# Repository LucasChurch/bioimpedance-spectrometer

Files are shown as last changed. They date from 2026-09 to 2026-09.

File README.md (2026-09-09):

# Bioimpedance Spectrometer Development Board
*Bench/research instrument. Not a certified medical device. Not for patient, diagnostic, or clinical use.*

## Overview

A discrete multi-frequency tetrapolar bioimpedance spectroscopy system. The intent of this project is to evaluate several bioimpedance current-source topologies from the literature via simulation, and validate the strongest candidate on a development board. Benchmarking results will be performed first against a resistor phantom and later on tissue. The board includes a low-noise, precision, analog front-end, and an STM32G0 microcontroller for digital lock-in filtering via a Goertzel filter, as well as the synchronous control of the excitation and sense chains.

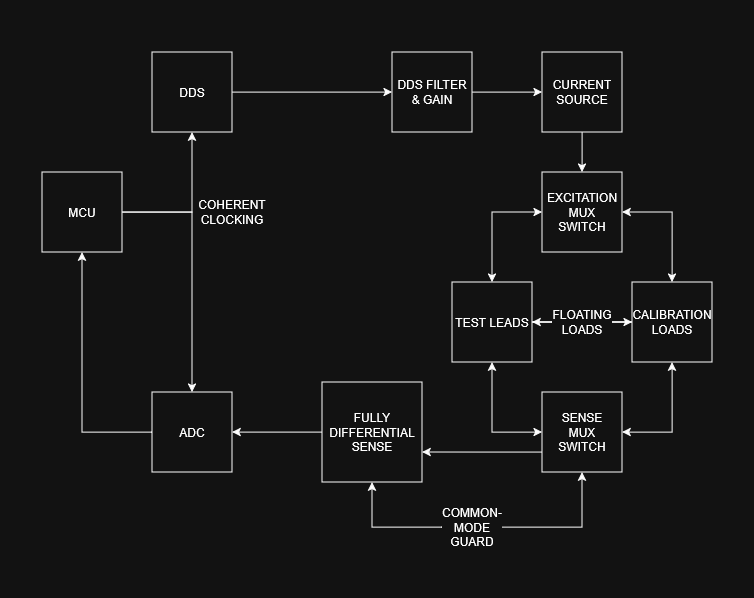
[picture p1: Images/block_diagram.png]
Block Diagram


## Quick Links

- [Schematic (PDF)](CAD/Bioimpedance%20Spectrometer/Outputs/Schematic%20PDF/BioZSpec.pdf)
- [PCB 3D Model (STEP)](CAD/Bioimpedance%20Spectrometer/Outputs/ExportSTEP/BioZ.step)
- [Bill of Materials](CAD/Bioimpedance%20Spectrometer/Outputs/BOM/Bill%20of%20Materials-BioZSpec.xlsx)

## Board Features

- **Measurement** - Multi-frequency bioimpedance spectroscopy. Software adjustable up to 250 kHz (default frequencies 10/50/100/250 kHz). Precision and repeatability designed to 0.25Ω magnitude accuracy and 0.2° phase accuracy. Can be pushed to 400 kHz.
- **Electrodes** - Tetrapolar (Kelvin connected) stainless steel dry contacts
- **Current Source** - Custom mirrored enhanced Howland current pump, 100µA RMS target. Simulated to <0.1% current deviation up to 10kOhm load at 250 kHz.
- **Sense Chain** - Fully differential, common-mode guarded, anti-aliasing filter
- **ADC** - 14-bit, 1 MSPS differential SAR ADC 
- **Excitation Waveform** - 16 MHz DDS-generated sine wave
- **Demodulation** - Software lock-in demodulation (I/Q) via Goertzel filter, coherent excitation/sampling/reference with a 48 MHz oscillator 
- **Calibration** - Three on-board precision complex loads for drift correction. External fixture for electrode compensation.
- **Power** - Rechargeable LiPo cell via USB-C. 5V boost charge pump for excitation. Software-controlled high-side switch for analog chain for power saving
- **MCU** - STM32G071

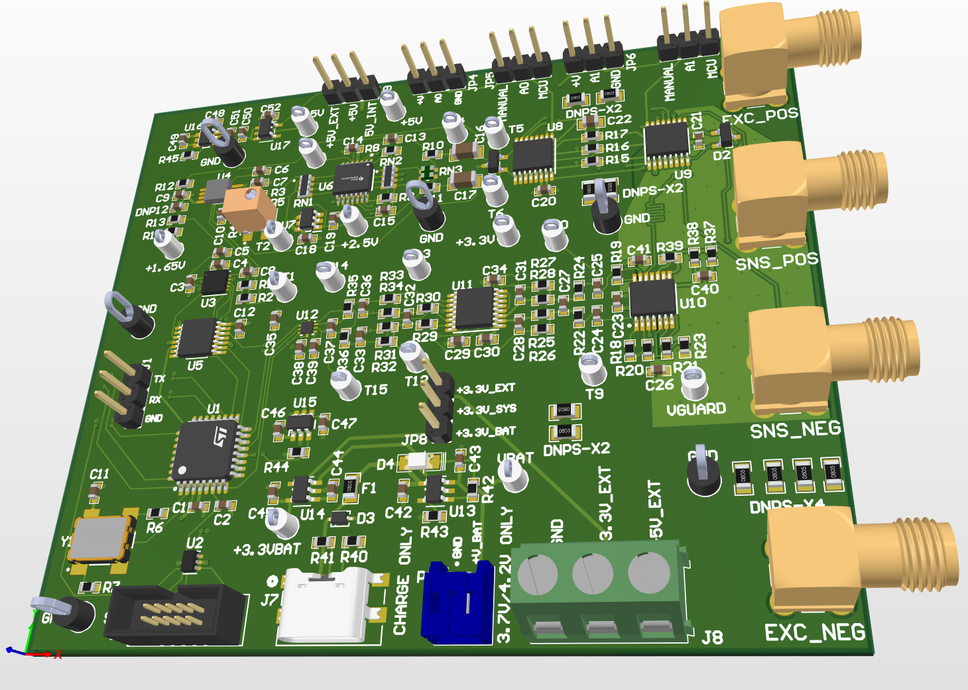
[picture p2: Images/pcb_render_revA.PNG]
PCB 3D Model


## Roadmap

- [x] Research
- [x] Requirements
- [x] Simulation / Schematic Capture
- [x] Layout
- [x] Board & Parts Acquisition
- [x] Calibration Jigs
- [ ] Firmware (*in progress*)
- [ ] Assembly
- [ ] Bring-up
- [ ] Design Verification & Benchmarking
- [ ] Final Documentation

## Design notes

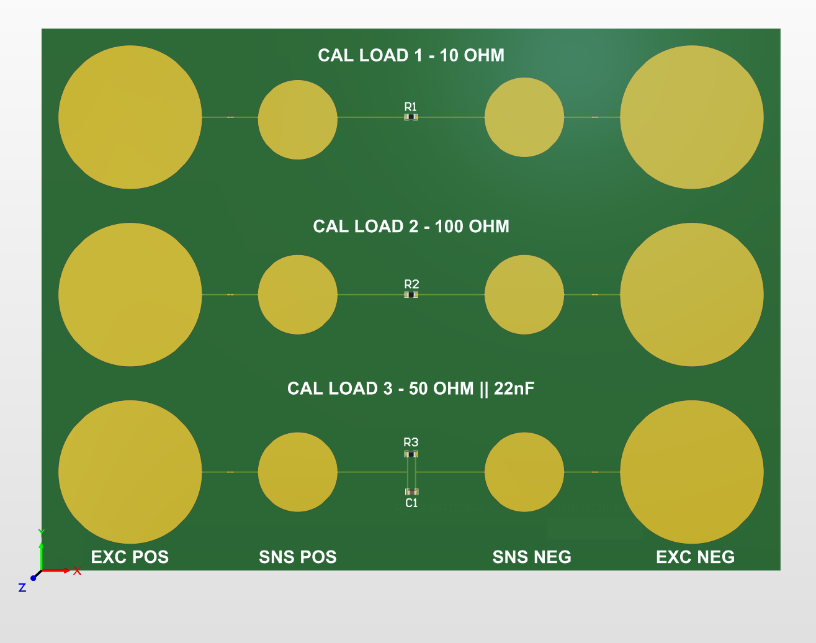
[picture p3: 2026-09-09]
Images/electrode_cal_jig.PNG

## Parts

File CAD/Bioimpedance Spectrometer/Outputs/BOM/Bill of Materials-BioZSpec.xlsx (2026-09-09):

Comment | Description | Designator | Footprint | LibRef | Quantity
10uF | CAP CER 10uF 6.3V X5R 0603, CAP CER 10UF 10V X7R 0603 | C1, C4, C14, C30, C35, C38, C39, C44, C45, C48, C50, C52 | 0603-CAP | CGA3E2C0G1H472J080AA | 12
100nF | CAP CER 100 NF 50V X7R 0603 | C2, C3, C5, C9, C11, C18, C19, C20, C21, C23, C29, C34, C40, C51 | 0603-CAP | CGA3E2C0G1H472J080AA | 14
1nF | CAP CER 1000 PF 50V C0G 0603 | C6, C37, C47 | 0603-CAP | CGA3E2C0G1H472J080AA | 3
100pF | CAP CER 100 PF 50V C0G 0603 | C7 | 0603-CAP | CGA3E2C0G1H472J080AA | 1
2.2uF | CAP CER 2.2UF 35V X5R 0603 | C8, C12, C24, C25, C42, C43, C46 | 0603-CAP | CGA3E2C0G1H472J080AA | 7
0.22uF | CAP CER 0.22UF 25V X7R 0603 | C10, C49 | 0603-CAP | CGA3E2C0G1H472J080AA | 2
10pF C0G | CAP CER 10PF 50V C0G 0603 | C13, C15 | 0603-CAP | CGA3E2C0G1H472J080AA | 2
100nF C0G 1% | CAP CER 0.1UF 1% 50V C0G/NP0 1206 | C16, C17 | 1206-CAP | GRM31C5C1H104JA01L | 2
22nF C0G 1% | CAP CER 0.022UF 50V C0G/NP0 0805 | C22 | 0805-CAP | GCM21B5C1H223JA16L | 1
10pF | CAP CER 10PF 50V C0G/NPO 0603 | C26, C41 | 0603-CAP | CGA3E2C0G1H472J080AA | 2
470pF | CAP CER 470PF 50V C0G 0603 | C27, C32 | 0603-CAP | CGA3E2C0G1H472J080AA | 2
82pF | CAP CER 82PF 50V C0G 0603 | C28, C31, C33, C36 | 0603-CAP | CGA3E2C0G1H472J080AA | 4
RCLAMP04022S.C |  | D1, D2 | SOT-23 3L | RCLAMP04022S.C | 2
TSD05DYFR | 5-V 60-A Unidirectional surge protection device 2-SOT -40 to 125 | D3 | TVS_SOD2_DYF_TEX-L | TSD05DYFR | 1
APT3216LZGCK | LED GREEN CLEAR 2SMD | D4 | 1206-LED | APT3216LZGCK | 1
MF-PSMF075X-2 | PTC RESET FUSE 6V 750MA 0805 | F1 | 0805-RES | 240R 0.1% | 1
CON3 | Connector | J1 | SIP3 | CON3 | 1
3220-10-0100-00 | Description | J2 | CONN_3220-10-0100-00_CNC | 3220-10-0100-00 | 1
RFPC-SMA27-F |  | J3, J4, J5, J6 | GRADCONN_RFPC-SMA27-F | RFPC-SMA27-F | 4
USB4135-GF-A | Description | J7 | CONN_USB4135-GF-A_GCT | USB4135-GF-A | 1
691213710003 | 213 Series 5MM Pitch Straight, Pcb Terminal Block, Through Hole, 3 Way | J8 | 691213710003 | CMP-1502-02527-3 | 1
JUMPER1X3 | CONN HEADER VERT 36POS 2.54MM | JP4, JP5, JP6, JP7, JP8, JP9 | JUMPER3 | 68001-203HLF | 6
S2B-PH-K-S(LF)(SN) | Male Header, Pitch 2 mm, 1 x 2 Position, Height 4.8 mm, Tail Length 3.4 mm, -25 to 85 degC, RoHS, Bulk | P1 | JST-S2B-PH-K-S_V | CMP-1755-00004-1 | 1
49.9R | RES SMD 49.9OHM 0.1% 1/10W 0603 | R1, R8, R9 | 0603-RES | 4.99K 0603 | 3
2.49k | RES SMD 2.49kOHM 0.1% 1/10W 0603 | R2 | 0603-RES | 4.99K 0603 | 1
100k | RES SMD 100KOHM 0.1% 1/10W 0603 | R3, R7, R37, R38 | 0603-RES | 4.99K 0603 | 4
100R | RES SMD 100OHM 0.1% 1/10W 0603 | R4 | 0603-RES | 4.99K 0603 | 1
1k | TRIMMER-SMD 4MM SQ MT CERMET Square / 12 turn / Sealed | Bourns PVG5A102C03R00 | R5 | TRIM_PVG5A102C03R00 | PVG5A102C03R00 | 1
22R | RES SMD 22OHM 0.1% 1/10W 0603 | R6, R18, R19, R39 | 0603-RES | 4.99K 0603 | 4
412R | RES SMD 412OHM 0.1% 1/10W 0603 | R10, R11, R26, R27, R32, R33, R42 | 0603-RES | 4.99K 0603 | 7
1M | RES SMD 1MOHM 0.1% 1/10W 0603 | R12, R13, R44 | 0603-RES | 4.99K 0603 | 3
10M | RES SMD 10MOHM 1% 1/10W 0603 | R14 | 0603-RES | 4.99K 0603 | 1
10R 0.05% | RES SMD 10OHM 0.05% 1/10W 0603 | R15 | 0603-RES | 4.99K 0603 | 1
100R 0.05% | RES SMD 100OHM 0.05% 1/10W 0603 | R16 | 0603-RES | 4.99K 0603 | 1
49.9R 0.05% | RES SMD 49.9OHM 0.05% 1/10W 0603 | R17 | 0603-RES | 4.99K 0603 | 1
10k | RES SMD 10K OHM 1% 1/10W 0603 | R20, R21, R43 | 0603-RES | 4.99K 0603 | 3
210R | RES SMD 210OHM 0.1% 1/10W 0603 | R22, R23, R24, R29, R30 | 0603-RES | 4.99K 0603 | 5
1.87k | RES SMD 1.87KOHM 0.1% 1/10W 0603 | R25, R28, R31, R34 | 0603-RES | 4.99K 0603 | 4
33R | RES SMD 33OHM 0.1% 1/10W 0603 | R35, R36 | 0603-RES | 4.99K 0603 | 2
5.1k | RES SMD 5.1K OHM 0.1% 1/10W 0603 | R40, R41 | 0603-RES | 4.99K 0603 | 2
10R | RES SMD 10OHM 0.05% 1/10W 0603 | R45 | 0603-RES | 4.99K 0603 | 1
10k | 4 resistor, resistor network in a 8 pin DIP package | RN1, RN2 | 1206 4-Resistor Network | ACASA1002S1002P1AT | 2
20k | 2 resistor, resistor network, 10k/10k 0.1% abs. and 0.05% rel., 0606, 25ppm | RN3 | 0606 2-RESISTOR NETWORK | ACASN1002S1002P1AT | 1
5002K | PC TEST POINT MINIATURE WHITE | T1, T2, T3, T4, T5, T6, T8, T9, T10, T11, T12, T13, T14, T15, T16, T17, T18, T19, T20, T21 | TESTPOINT White | 5002K | 20
5011K | PC TEST POINT MULTIPURPOSE BLACK | T22, T23, T24, T25, T26, T27 | TESTPOINT Black | 5011K | 6
STM32G071KBT6N | IC MCU 32BIT 128KB FLASH 32LQFP | U1 | FP-LQFP32-5V-IPC_C | CMP-12105-000115-1 | 1
D3V3F4U6S-7 | Description | U2 | SOT-363_DIO | D3V3F4U6S-7 | 1
AD9837BCPZ-RL7 | Direct Digital Synthesis IC 10 b 16 MHz 28 b Tuning 10-LFCSP-WD (3x3) | U3 | LFCSP-WD (3x3) - 10 Pin EPAD | AD9837BCPZ-RL7 | 1
AD8692ARMZ-REEL | Double Channel Wide Bandwidth Operational Amplifier, 10 MHz BW, 5 V/us SR, Industrial, 8-pin SOP (RM-8), Reel | U4 | ADI-RM-8_M | CMP-0384-01747-1 | 1
SN74CBTLV3125PWR | 3.3-V, 1:1 (SPST), 4-channel FET bus switch with powered-off protection 14-TSSOP -40 to 85 | U5 | PW0014A-IPC_A | SN74CBTLV3125PWR | 1
OPA4192IPWR | IC OPAMP GP 4 CIRCUIT 14TSSOP | U6 | FP-PW0014A-IPC_C | CMP-04895-000439-1 | 1
MCP1502T-25E_CHY | Series Voltage Reference IC Fixed 2.5V V +/-0.1% 20 mA SOT-23-6 | U7 | SOT95P280X145-6N | MCP1502T-25E_CHY | 1
TMUX1209PWR | 5-V, 4:1, 2-channel general-purpose multiplexer with 1.8-V input logic control 16-TSSOP -40 to 125 | U8, U9 | PW0016A_N | TMUX1209PWR | 2
OPA4377AIPWR | Low-Cost, Low Noise, 5.5 MHz CMOS Operational Amplifier, 2.2 to 5.5 V, -40 to 125 degC, 14-pin SOP (PW14), Green (RoHS & no Sb/Br) | U10 | PW0014A_N | CMP-0272-01748-3 | 1
THS4552IPWT | Dual Channel, Low-Noise, Precision, 150-MHz, Fully Differential Amplifier 16-TSSOP -40 to 125 | U11 | PW0016A_N | THS4552IPWT | 1
ADS7054IRUGR | 14-Bit, 1MSPS, Differential Input, Small-Size Low-Power SAR ADC 8-X2QFN -40 to 125 | U12 | 8-X2QFN (1.5x1.5) | ADS7054IRUGR | 1
MCP73831T-2ACI/OT | IC CONTROLLR LI-ION 4.2V SOT23-5 | U13 | SOT23_DBV_TEX-M | CMP-0133-00143-2 | 1
TPS7A0233DBVR | 200mA, nanopower-IQ (25 nA), low-dropout (LDO) voltage regulator with enable 5-SOT-23 -40 to 125 | U14 | SOT23_DBV_TEX-M | TPS7A0230PDBVR | 1
TPS22917DBVT | 5.5-V, 2-A, 80-mÎ© , 10-nA leakage load switch adj. rise time and adj output discharge 6-SOT-23 -40 to 125 | U15 | DBV0006_N | TPS22917DBVT | 1
REG71055DDCR | 5.5 V, Buck / Boost Charge Pump, 60 mA, 3 to 5.5 V Input with 2-Cell Alkaline / Nixx Input, -40 to 85 degC, 6-pin SOT23 (DDC6), Green (RoHS & no Sb/Br) | U16 | DDC0006A_M | CMP-0391-00039-2 | 1
TPS7A2050PDBVR | 200mA, nanopower-IQ (25 nA), low-dropout (LDO) voltage regulator with enable 5-SOT-23 -40 to 125 | U17 | SOT23_DBV_TEX-M | TPS7A0230PDBVR | 1
831018043 |  | Y1 | WE-SPXO_CFPS-73 | WE-SPXO_CFPS-73 | 1

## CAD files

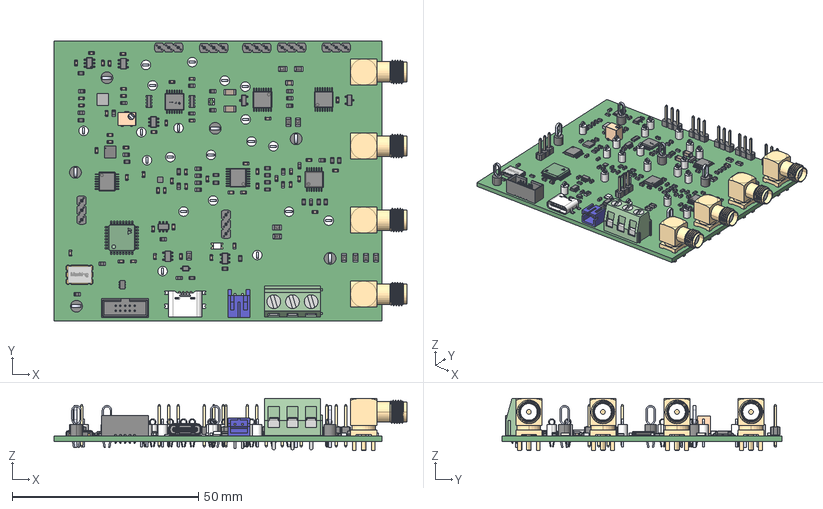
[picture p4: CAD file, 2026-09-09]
CAD/Bioimpedance Spectrometer/Outputs/ExportSTEP/BioZ.step
94.7 x 75.0 x 14.0 mm
BODY_MK06A
LEAD_MK06A x 6
BODY-TSSOP x 4
LEAD-TSSOP x 62
PIN1 x 4
PVG5A102C03R00
Resistor-0805 x 11
Pins
Cover
BODY-SOT x 6
LEAD-SOT x 29
LEAD-DUMMY x 3
BODY-QFN
PIN1-ID
BODY_MTC14
LEAD_MTC14 x 14
Texas Instruments CD40106BPWR 1
Texas Instruments CD40106BPWR 2 x 16
Texas Instruments CD40106BPWR 2_MIR x 7
Texas Instruments
Extruded
AD9837BCPZ-RL7
IC_BODY
circle
IC_LEG x 32
STMicroelectronics
Keystone-5011 x 6
keystone-5002 x 20
ACASA1002S1002P1AT x 2
S2B-PH-K-S
68000 gold body_03 x 7
pin^68000 Gold x 21
6912137100xx_MASS x 3
6912137100xx_VIS x 3
6912137100xx_PIN x 3
RFPC-SMA27-F x 4
3220-xx-0100-00 body_10
Pin^3220-xx-0100-00 x 10
LED-1206

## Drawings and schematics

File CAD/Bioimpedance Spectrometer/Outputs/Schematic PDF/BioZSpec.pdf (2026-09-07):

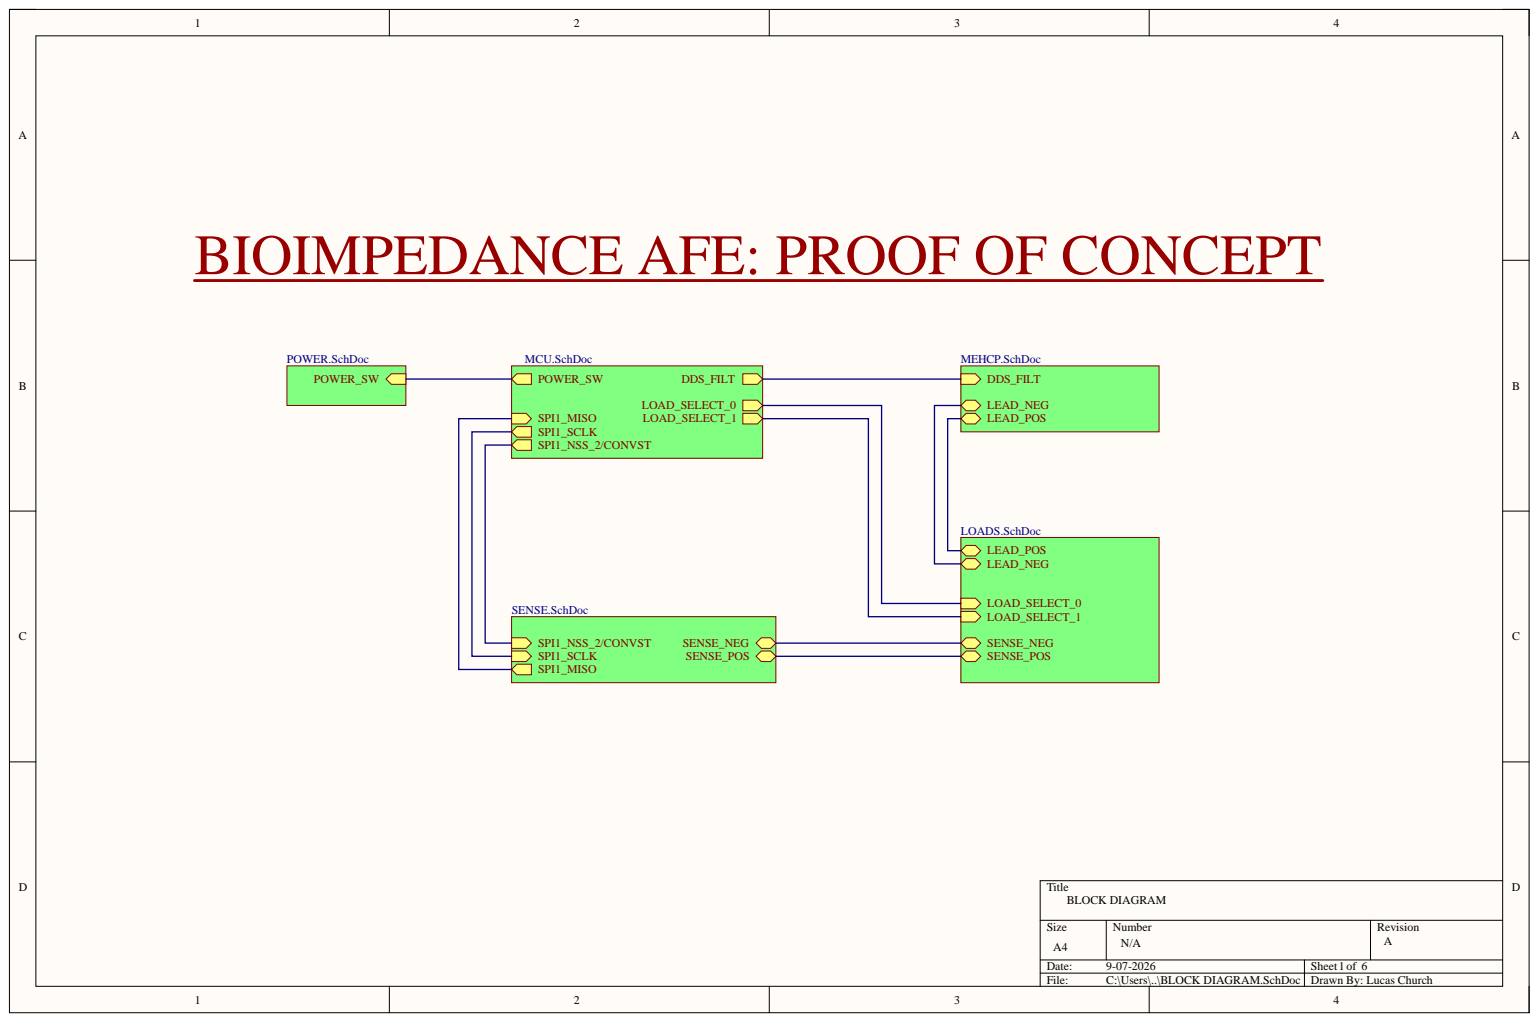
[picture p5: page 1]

BIOIMPEDANCE AFE: PROOF OF CONCEPT

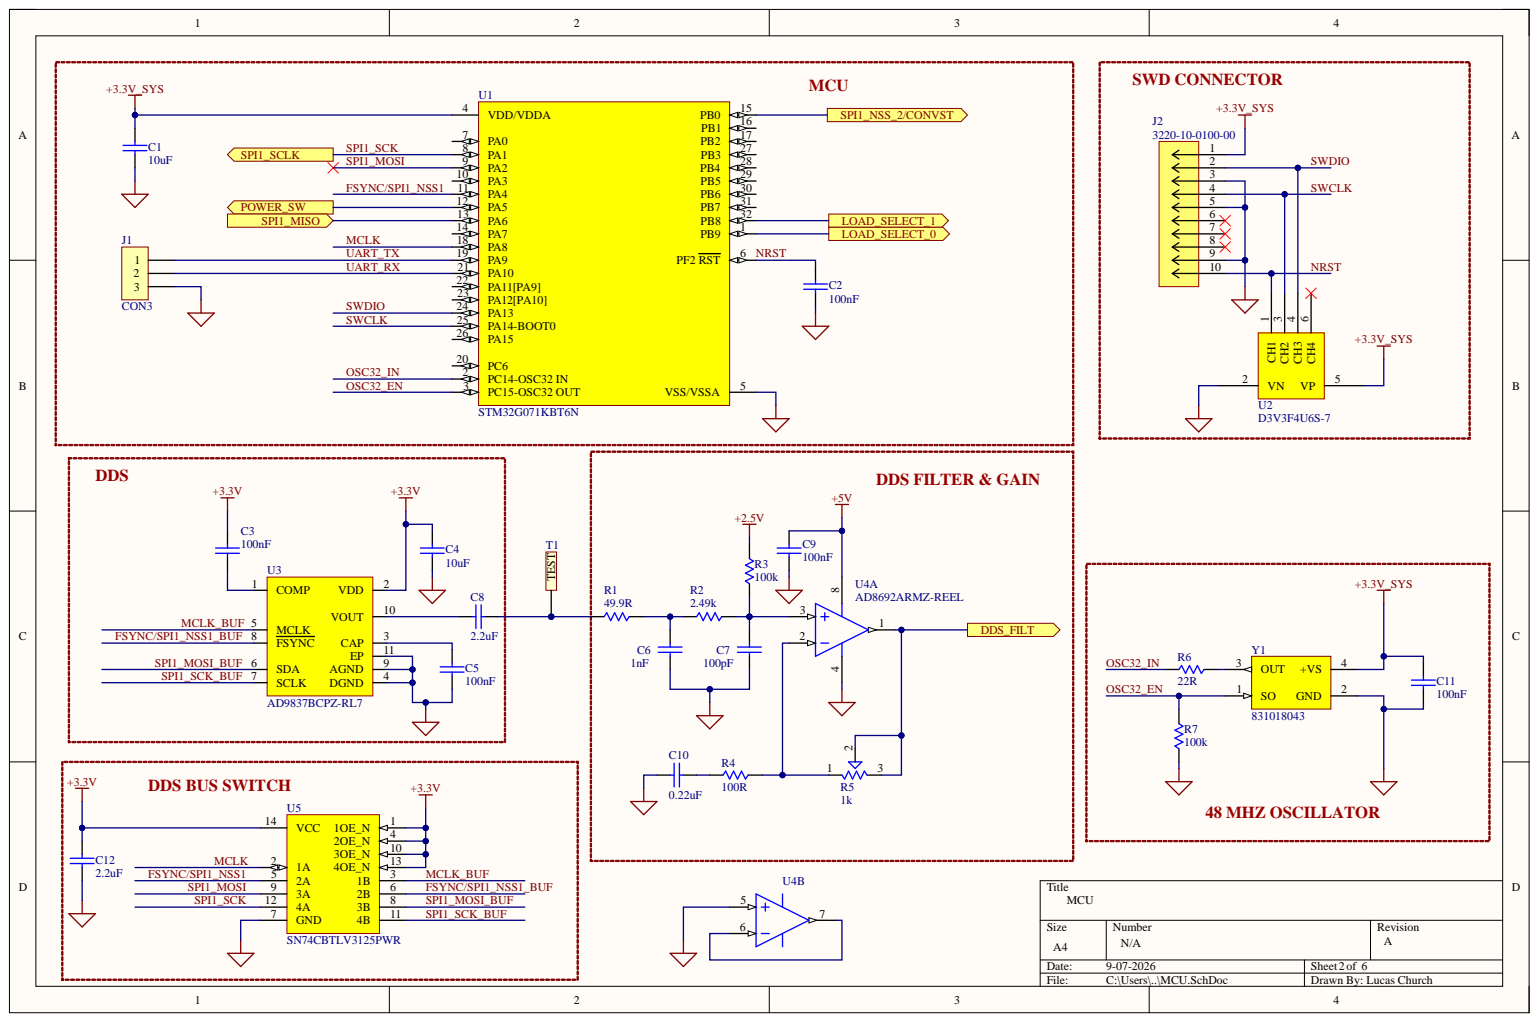
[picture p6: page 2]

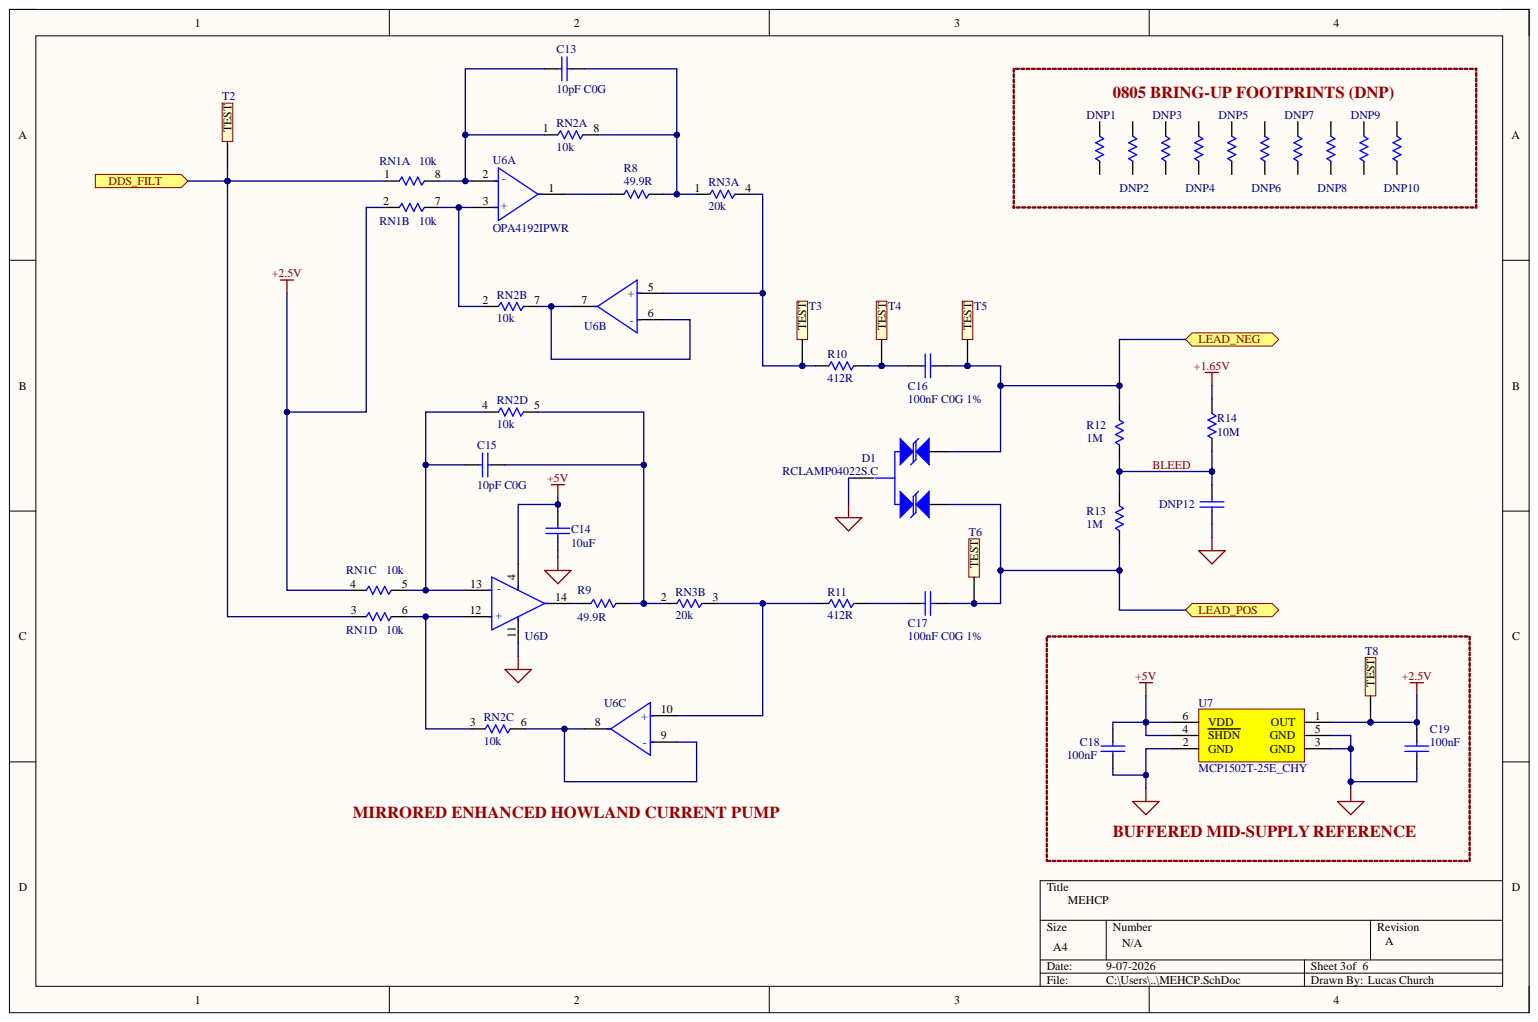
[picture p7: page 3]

0805 BRING-UP FOOTPRINTS (DNP)

MIRRORED ENHANCED HOWLAND CURRENT PUMP

BUFFERED MID-SUPPLY REFERENCE

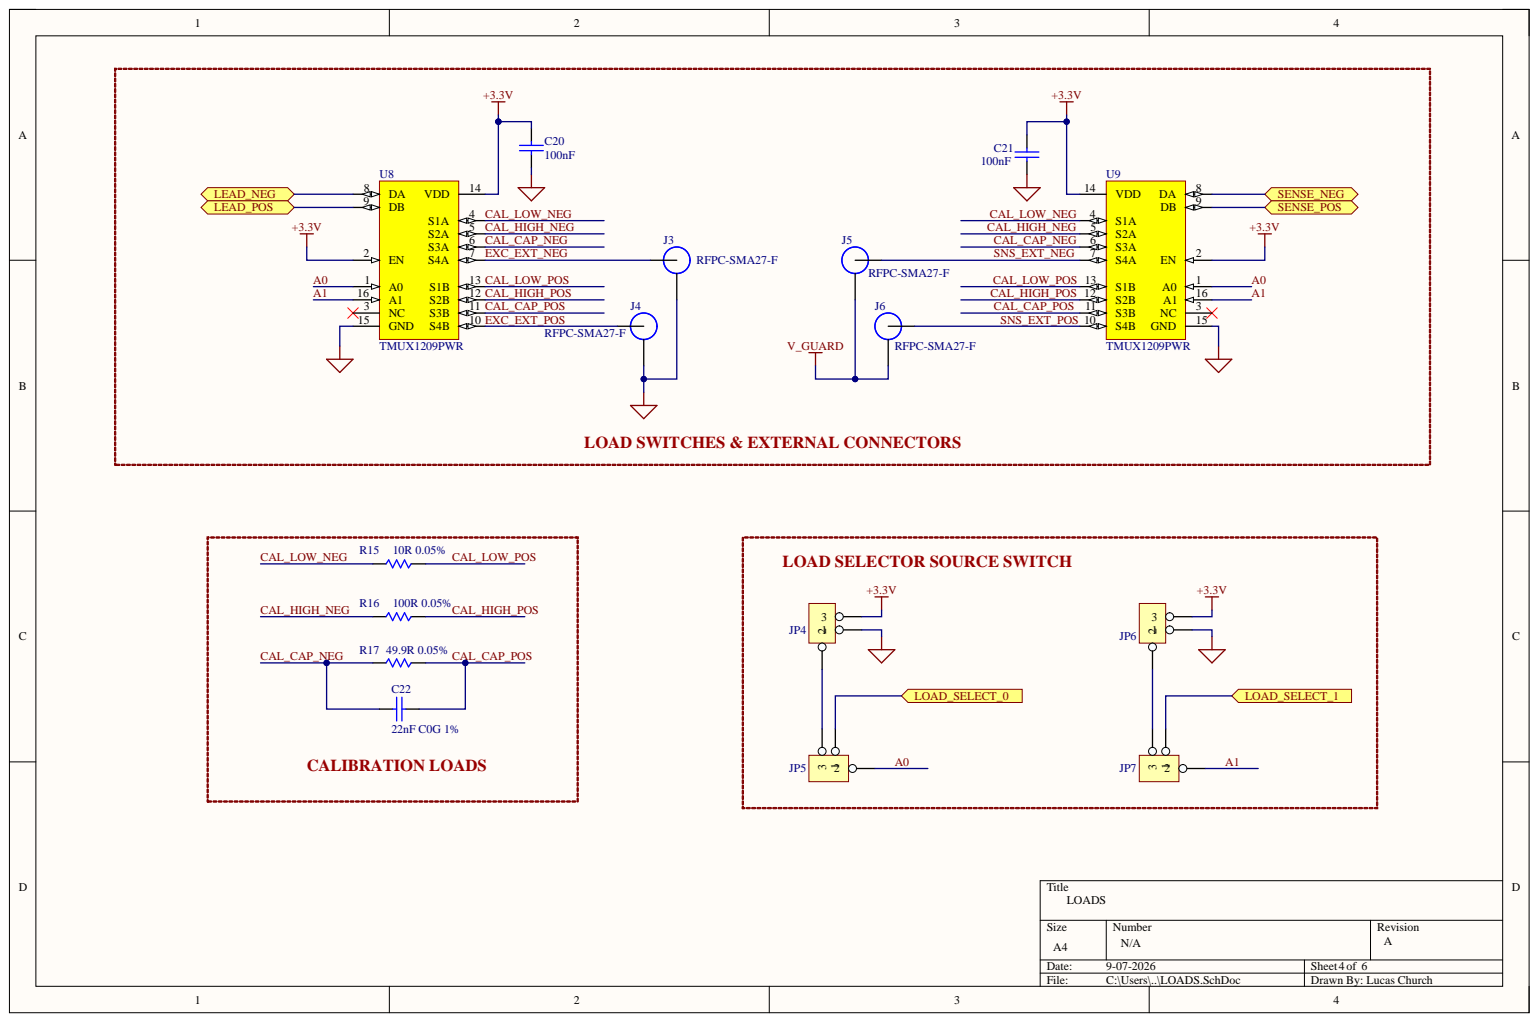
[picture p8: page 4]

LOAD SWITCHES & EXTERNAL CONNECTORS

LOAD SELECTOR SOURCE SWITCH

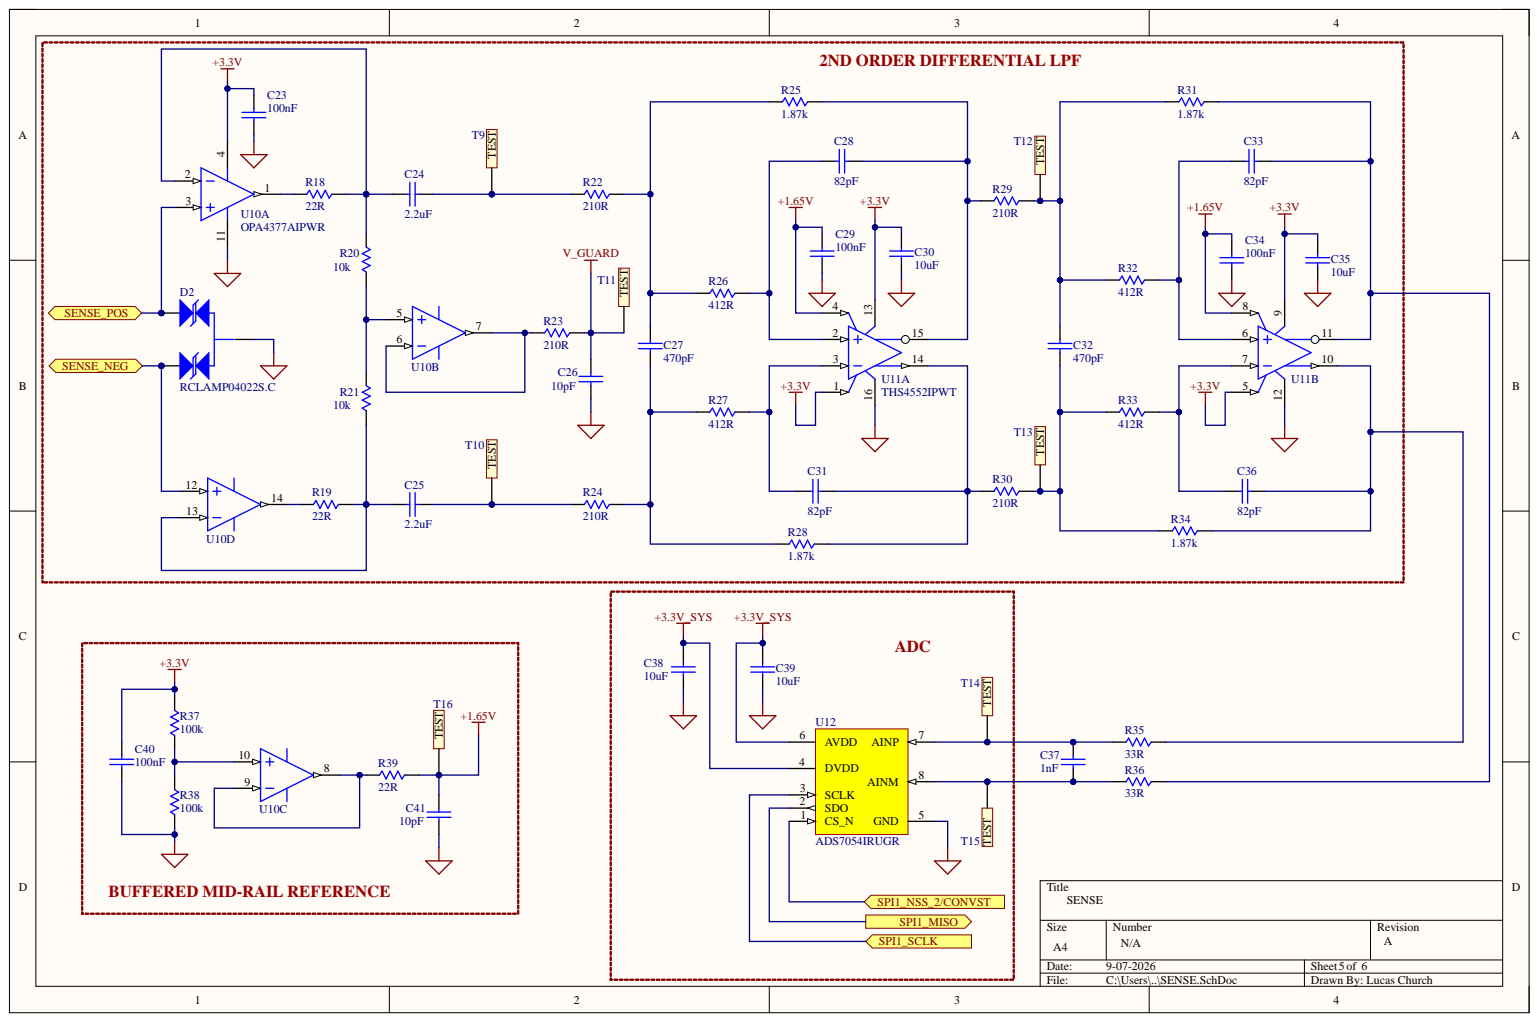
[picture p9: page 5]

BUFFERED MID-RAIL REFERENCE

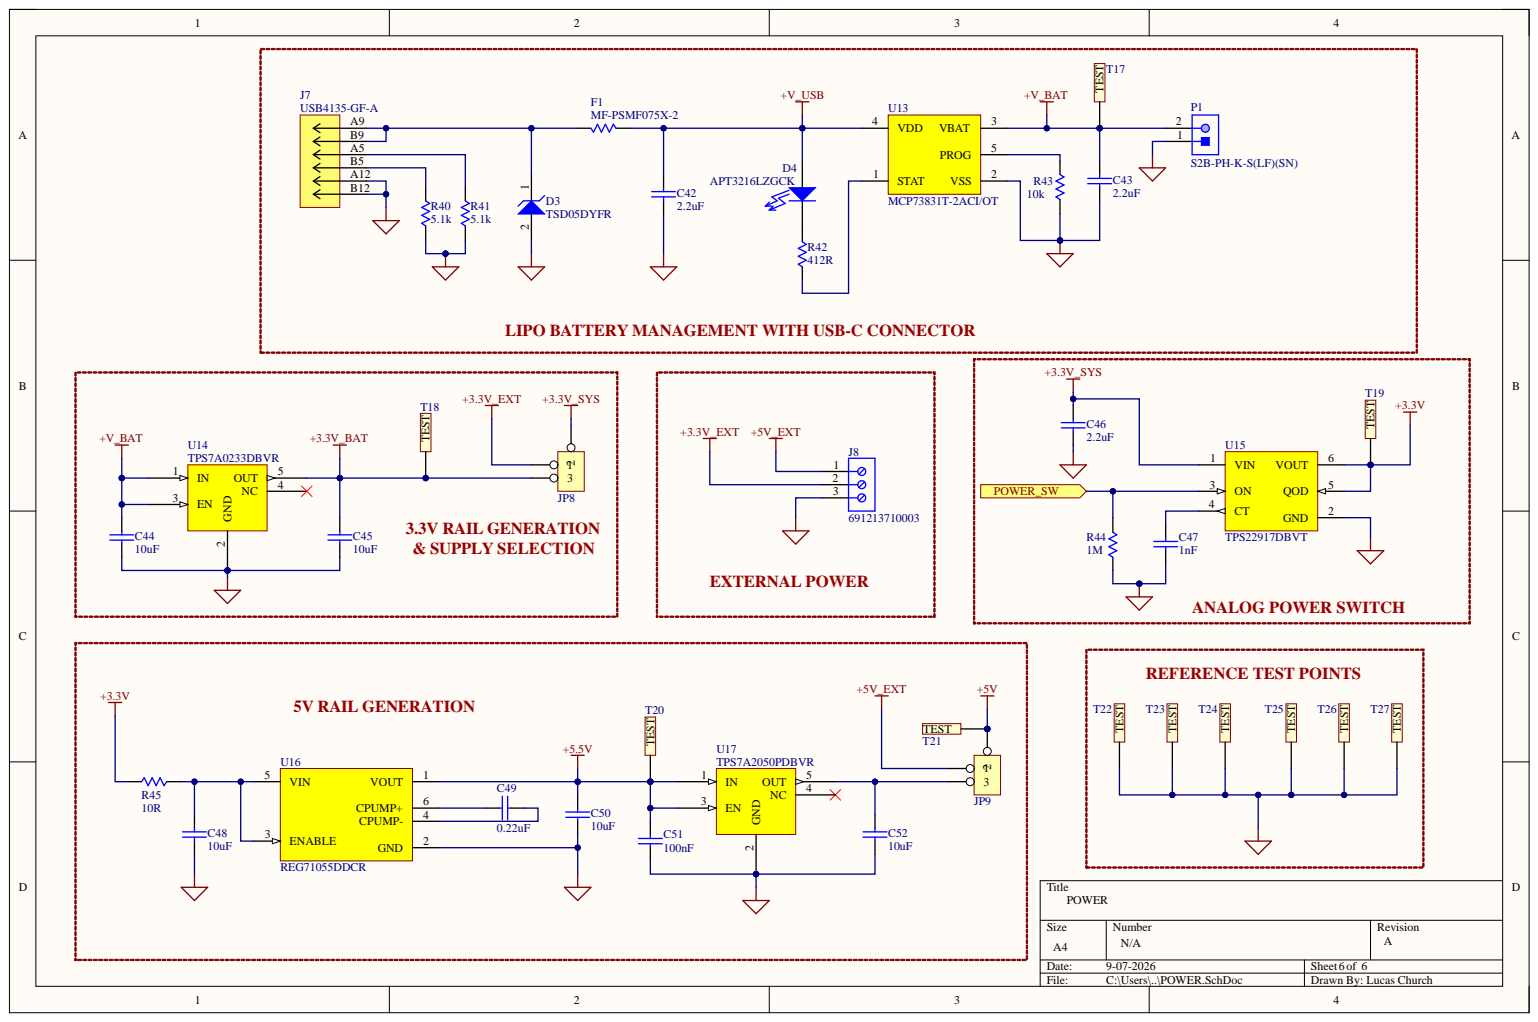
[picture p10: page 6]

LIPO BATTERY MANAGEMENT WITH USB-C CONNECTOR

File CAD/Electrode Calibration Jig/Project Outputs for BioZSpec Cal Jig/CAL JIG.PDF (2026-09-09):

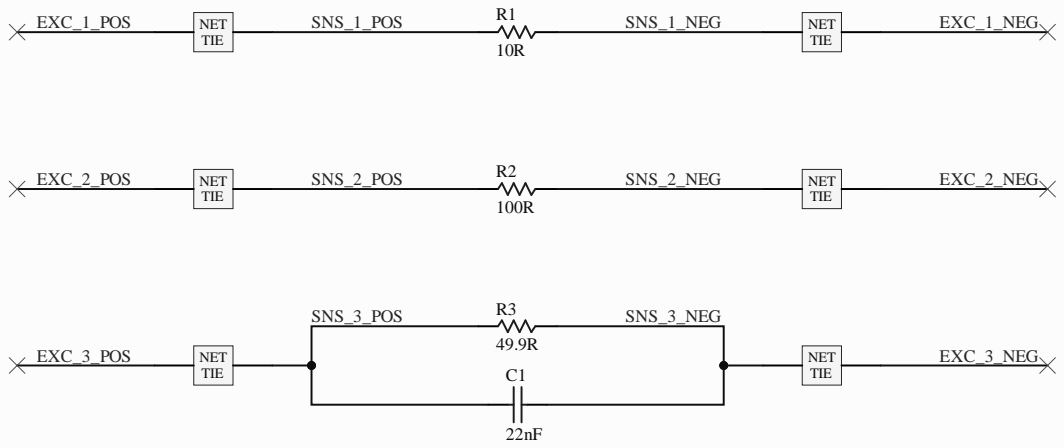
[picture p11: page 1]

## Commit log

2026-09-07 Inital commit. Current source done.
    [BioZ.PcbLib, BioZ.SchLib, BioZ_RevA.PrjPcb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]
2026-09-07 Swapped MCU to STM32G0 for SPI/ADC speed
    [BioZ.PcbLib, BioZ.SchLib, MCU.SchDoc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]
2026-09-07 Added 48 MHz reference oscillator.
    [BioZ.PcbLib, BioZ.SchLib, MCU.SchDoc]
2026-09-07 Fixed mid-supply reference buffer polarity.
    [MCU.SchDoc, Sheet1.SchDoc]
2026-09-07 Added load sheet. Moved subcircuits.
    [LOADS.SchDoc, Sheet1.SchDoc, Sheet2.SchDoc]
2026-09-07 Schematic cleanup.
    [LOADS.SchDoc, MCU.SchDoc, MEHCP.SchDoc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]
2026-09-07 Swwapped to 14-bit version of ADC.
    [BioZ.PcbLib, BioZ.SchLib, Sheet1.SchDoc]
2026-09-07 Added sense-side buffers
    [BioZ.SchLib, Sheet1.SchDoc]
2026-09-07 Add anti-aliasing filter.
    [BioZ.SchLib, MCU.SchDoc, Sheet1.SchDoc]
2026-09-07 Added placeholder charge bucket.
    [Sheet1.SchDoc]
2026-09-07 Added skeleton simulation for input MFB stage.
2026-09-07 Added preliminary FDA simulation
    [BioZ_RevA.PrjPcb]
2026-09-07 Renamed sense simulation. Updated with intended passive values.
    [SENSE.SchDoc, Sheet1.SchDoc]
2026-09-07 Added FDAs to schematic
    [SENSE.SchDoc]
2026-09-07 Added 5.5V boost converter
    [LOADS AND POWER.SchDoc]
2026-09-07 Swapped boost converter. Had wrong output.
    [LOADS AND POWER.SchDoc]
2026-09-07 Revamped input power modules.
    [BioZ.PcbLib, BioZ.SchLib, BioZ_RevA.PrjPcb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]
2026-09-07 Several minor corrections. Added 2.5V reference.
    [BioZ.PcbLib, BioZ.SchLib, LOADS.SchDoc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]
2026-09-07 Added test points. Added guard trace. Added external 5V
    [BioZ_RevA.PrjPcb, MCU.SchDoc, MEHCP.SchDoc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]
2026-09-07 Fixed 1.65V reference. Previously used 1.6V IC.
    [SENSE.SchDoc]
2026-09-07 Fixed 5V LDO. Used the part number for 2.5V version.
    [POWER.SchDoc, SENSE.SchDoc]
2026-09-07 Replaced FDAs with THS4552 as upgrade at small cost.
    [BioZ.PcbLib, BioZ.SchLib, SENSE.SchDoc]
2026-09-07 Increased overall sense gain to 80 from 40
    [SENSE.SchDoc]
2026-09-07 Added cap to NRST to prevent unwanted resets
    [MCU.SchDoc]
2026-09-07 Fixed 3.3V LDO part number
    [MCU.SchDoc, MEHCP.SchDoc, POWER.SchDoc]
2026-09-07 Changed DDS LPF to account for output Z
    [MCU.SchDoc]
2026-09-07 Removed sense buffer isolation resistors
    [SENSE.SchDoc]
2026-09-07 Modified complex calibration load. Values will change at bring-up
    [LOADS.SchDoc]
2026-09-07 Changed battery IC for PCM packages
    [POWER.SchDoc]
2026-09-07 Added SMA connectors for external loads
    [BioZ.PcbLib, BioZ.SchLib, BioZ_RevA.PrjPcb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]
2026-09-07 Added ESD protection to sense & SWD
    [BioZ.PcbLib, BioZ.SchLib, MCU.SchDoc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]
2026-09-07 Fixed DDS filter to have +5V
    [MCU.SchDoc, POWER.SchDoc]
2026-09-07 Added TVS to USB line
    [BioZ.PcbLib, BioZ.SchLib, POWER.SchDoc]
2026-09-07 Fixed symbols and some off-sheet connectors
    [BioZ.SchLib, MCU.SchDoc, MEHCP.SchDoc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]
2026-09-07 Primary review started. Fixed HCP op-amp supply pins
    [LOADS.SchDoc, MEHCP.SchDoc, POWER.SchDoc]
2026-09-07 Fixed USB-C pinout
    [MEHCP.SchDoc, POWER.SchDoc]
2026-09-07 Added bypass DNP footprints and fixed more symbols
    [BioZ.PcbLib, BioZ.SchLib, MCU.SchDoc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]
2026-09-07 Added test point to V_GUARD
    [POWER.SchDoc, SENSE.SchDoc]
2026-09-07 Added DDS filter simulation. Design needs to be fixed
    [MCU.SchDoc, SENSE.SchDoc]
2026-09-07 Began annotation, swapped sense buffer for availability
    [BioZ.PcbLib, BioZ.SchLib, LOADS.SchDoc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]
2026-09-07 Annotation complete
    [LOADS.SchDoc, MCU.SchDoc, POWER.SchDoc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]
2026-09-07 Cleared ERCs, all connection issues
    [BLOCK DIAGRAM.SchDoc, BioZ_RevA.PrjPcb, LOADS.SchDoc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]
2026-09-07 Review complete. Ready for layout. Added UART for debugging.
    [BLOCK DIAGRAM.SchDoc, BioZ.PcbLib, BioZ.SchLib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]
2026-09-07 Placement complete (minus bring-up DNPs)
    [BioZ.PcbDoc, BioZ.PcbLib, BioZ.SchLib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]
2026-09-07 Small interconnect error fixed. DDS SPI buffer added
    [BLOCK DIAGRAM.SchDoc, BioZ.PcbDoc, BioZ.PcbLib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]
2026-09-07 File structure clean-up.
    [Bill of Materials-BioZSpec.xlsx, BioZ.PcbDoc, BioZ.step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]
2026-09-07 Updated outputs and project structure file
    [Bill of Materials-BioZSpec.xlsx, BioZ.step, BioZSpec.PrjPcb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]
2026-09-09 Re-added ground stitch pattern
    [Bill of Materials-BioZSpec.xlsx, BioZ.PcbDoc, BioZ.step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]
2026-09-09 Initial upload of cal jig. Slight folder restructure
    [BLOCK DIAGRAM.SchDoc, Bill of Materials-BioZSpec.xlsx, BioZ.PcbDoc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]
